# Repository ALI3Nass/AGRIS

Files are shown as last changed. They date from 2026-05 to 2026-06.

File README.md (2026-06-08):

# AGRIS

A computer vision-driven laser targeting system mounted on a remotely controlled mecanum platform. The system detects geometric shapes in a live camera feed and automatically aims a laser at them using a pan/tilt servo gimbal — while a separate subsystem handles omnidirectional drive via a controller.

---

<p align="center">
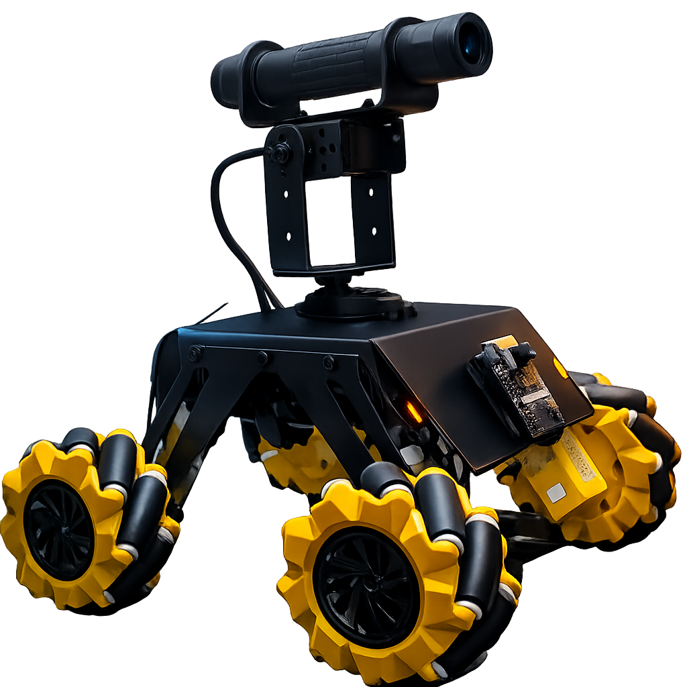
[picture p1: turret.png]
AGRIS turret assembly
  
</p>

---

## How it works

Two independent subsystems share the same laser-cut metal frame:

**Vision / Targeting**
The OV2640 camera streams MJPEG video over Wi-Fi to `agris.py` on a Linux host. OpenCV detects target shapes, calculates the angular error from the frame center, and sends absolute servo positions via UDP to the AI-Thinker ESP32. The ESP32 drives two MG996R servos and gates the laser on confirmed lock.

**Drive**
An ESP32-S1 connects to a DualShock 4 over Bluetooth (Bluepad32) and independently drives four mecanum wheels — full omnidirectional movement, strafing, and in-place rotation.

```
OV2640 (fixed to frame)
  → MJPEG stream over Wi-Fi
  → agris.py on PC  (shape detection, FOV-aware proportional control)
  → UDP :4210  →  AI-Thinker ESP32
                    ├── MG996R pan servo   (GPIO 12)
                    ├── MG996R tilt servo  (GPIO 13)
                    └── Laser module       (GPIO 2)

DualShock 4 (Bluetooth)
  → ESP32-S1
      ├── Mecanum FL
      ├── Mecanum FR
      ├── Mecanum RL
      └── Mecanum RR
```

---

## Hardware

| Component | Details |
|---|---|
| Vision + servo controller | AI-Thinker ESP32-CAM (OV2640) |
| Drive controller | ESP32-S1 |
| Camera | OV2640 — QVGA (320×240) for low latency |
| Servos | MG996R × 2 (pan / tilt) |
| Laser | LaserTree LT-40W-F23 (~5 W optical, 12 V / 1.8 A, PWM via signal wire) |
| Controller | DualShock 4 over Bluetooth |
| Frame | Laser-cut metal — DXF files in `CAD_Design/` |

---

## Repository layout

```
agris.py                     Python tracking app (GUI, detection, UDP sender)
AGRIS_AiThinker/
  AGRIS_AiThinker.ino        AI-Thinker firmware (MJPEG stream + UDP + servo/laser)
ESP32S1/
  ESP32S1.ino                Mecanum drive firmware (DualShock 4 → motors)
CAD_Design/
  part-1.dxf
  part-2.dxf
  part-3.dxf
  turret.jpg
```

---

## Setup

**Python dependencies**
```bash
pip install opencv-python numpy pillow requests
```

**Arduino libraries**
`esp32-camera` · `ESP32Servo` · `AsyncUDP` · `Bluepad32`

Flash `AGRIS_AiThinker.ino` to the AI-Thinker board and `ESP32S1.ino` to the drive controller, then run:
```bash
python agris.py
```

---

## Vision pipeline

Adaptive thresholding + contour classification. Detectable shapes:

- Rectangle
- Square
- Circle
- Plus cross `+`
- X cross `×`

Target priority and per-shape enable/disable are configurable at runtime in the GUI.

---

## Communication protocol

UDP packet sent from `agris.py` → ESP32 on port **4210**:

```
PAN:xxxx,TILT:xxxx,LASER:x
```

Values are microseconds for the servo signal. `LASER` is `0` or `1`.

**Servo ranges**

| Axis | Min | Center | Max |
|---|---|---|---|
| Pan | 500 µs | 1632 µs | 2500 µs |
| Tilt | 1050 µs | 1500 µs | 2200 µs |

Tracking uses one-shot absolute positioning — servo angles are computed directly from pixel error and camera FOV, not accumulated incrementally.

---

## Notes

- The laser pin (GPIO 2) is held LOW during boot to prevent accidental firing on startup.
- AI-Thinker board uses `CAMERA_FB_IN_DRAM` with `fb_count=1` (no PSRAM).
- An ESP32-S3 sketch is available as an alternate board target for the vision/servo role.
- The phone camera (IP Webcam → OpenCV HTTP URL) works as a drop-in fallback if the ESP32-CAM is unavailable.

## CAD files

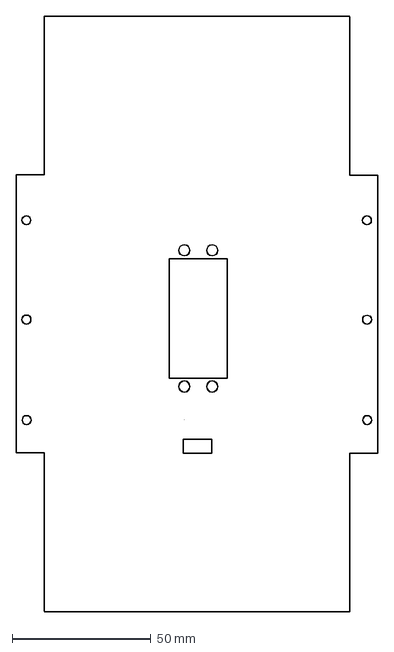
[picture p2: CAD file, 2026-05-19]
CAD_Design/part-2.dxf
130.0 x 214.2 mm

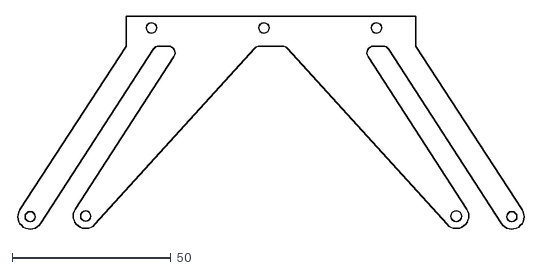
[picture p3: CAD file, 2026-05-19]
CAD_Design/part-1.dxf
160.8 x 67.7

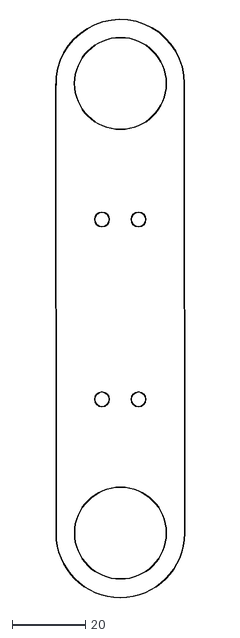
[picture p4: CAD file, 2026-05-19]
CAD_Design/part-3.dxf
35.2 x 158.3

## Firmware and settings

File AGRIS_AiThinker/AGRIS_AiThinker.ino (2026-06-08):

#include "esp_camera.h"
#include <WiFi.h>
#include <WebServer.h>
#include <ESP32Servo.h>
#include <AsyncUDP.h>

// ── WiFi ─────────────────────────────────────────────────────
const char* SSID     = "Pixel 9";
const char* PASSWORD = "12341234";
#define UDP_PORT 4210

// ── Pin Definitions ──────────────────────────────────────────
// No SD card used → GPIO 12 and 13 are free
// GPIO 2 is safe for digital output (ignore the brief boot LED blink)
#define SERVO_PAN_PIN   12    // ⚠ strapping pin — leave floating/low during boot
#define SERVO_TILT_PIN  13
#define LASER_PIN        2

// ── Camera Pins — AI-Thinker ESP32-CAM (OV2640) ──────────────
// Source: randomnerdtutorials.com/esp32-cam-ai-thinker-pinout/
#define PWDN_GPIO_NUM   32    // Active LOW — must be driven
#define RESET_GPIO_NUM  -1
#define XCLK_GPIO_NUM    0
#define SIOD_GPIO_NUM   26
#define SIOC_GPIO_NUM   27
#define Y9_GPIO_NUM     35
#define Y8_GPIO_NUM     34
#define Y7_GPIO_NUM     39
#define Y6_GPIO_NUM     36
#define Y5_GPIO_NUM     21
#define Y4_GPIO_NUM     19
#define Y3_GPIO_NUM     18
#define Y2_GPIO_NUM      5
#define VSYNC_GPIO_NUM  25
#define HREF_GPIO_NUM   23
#define PCLK_GPIO_NUM   22

// ── Servo range — synced with agris.py ───────────────────────
#define PAN_SERVO_MIN     500
#define PAN_SERVO_MAX    2500
#define PAN_SERVO_CENTER 1632
#define TILT_SERVO_MIN   1050
#define TILT_SERVO_MAX   2200
#define TILT_SERVO_CENTER 1500

Servo panServo;
Servo tiltServo;
WebServer server(80);
AsyncUDP udp;

int  currentPan  = PAN_SERVO_CENTER;
int  currentTilt = TILT_SERVO_CENTER;
bool laserOn     = false;

// ── Camera Setup ─────────────────────────────────────────────
void setupCamera() {
  camera_config_t config;

  // LEDC channel/timer: camera driver uses LEDC for XCLK generation.
  // Timers 0 and 1 can conflict — use 0 here as the camera itself
  // manages XCLK via LEDC_CHANNEL_0 / LEDC_TIMER_0 internally.
  config.ledc_channel = LEDC_CHANNEL_0;
  config.ledc_timer   = LEDC_TIMER_0;

  config.pin_d0    = Y2_GPIO_NUM;
  config.pin_d1    = Y3_GPIO_NUM;
  config.pin_d2    = Y4_GPIO_NUM;
  config.pin_d3    = Y5_GPIO_NUM;
  config.pin_d4    = Y6_GPIO_NUM;
  config.pin_d5    = Y7_GPIO_NUM;
  config.pin_d6    = Y8_GPIO_NUM;
  config.pin_d7    = Y9_GPIO_NUM;
  config.pin_xclk  = XCLK_GPIO_NUM;
  config.pin_pclk  = PCLK_GPIO_NUM;
  config.pin_vsync = VSYNC_GPIO_NUM;
  config.pin_href  = HREF_GPIO_NUM;

  // AI-Thinker uses older esp32-camera API naming (pin_sscb_*)
  // If your esp32-camera library uses pin_sccb_*, swap these:
  config.pin_sscb_sda = SIOD_GPIO_NUM;
  config.pin_sscb_scl = SIOC_GPIO_NUM;

  config.pin_pwdn  = PWDN_GPIO_NUM;   // GPIO 32 — must be set LOW to power camera
  config.pin_reset = RESET_GPIO_NUM;  // -1 = software reset

  config.xclk_freq_hz = 20000000;
  config.pixel_format = PIXFORMAT_JPEG;
  config.frame_size   = FRAMESIZE_QVGA;  // 320x240 — optimal for tracking
  config.jpeg_quality = 12;              // 0=best, 63=worst
  config.fb_count     = 2;

  // AI-Thinker PSRAM malloc failed — use internal DRAM instead.
  // Limit fb_count to 1 to avoid running out of DRAM.
  config.fb_location = CAMERA_FB_IN_DRAM;
  config.fb_count    = 1;
  config.grab_mode   = CAMERA_GRAB_WHEN_EMPTY;

  esp_err_t err = esp_camera_init(&config);
  if (err != ESP_OK) {
    Serial.printf("Camera init FAILED: 0x%x\n", err);
    Serial.println("Check: PSRAM present? Try fb_location = CAMERA_FB_IN_DRAM if this fails.");
  } else {
    Serial.println("Camera init OK");
  }

  // Sensor tuning after init
  sensor_t* s = esp_camera_sensor_get();
  if (s) {
    s->set_framesize(s,     FRAMESIZE_QVGA);
    s->set_quality(s,       12);
    s->set_brightness(s,     1);  // -2 to 2
    s->set_contrast(s,       1);  // -2 to 2
    s->set_saturation(s,     0);  // -2 to 2
    s->set_whitebal(s,       1);  // auto white balance
    s->set_awb_gain(s,       1);
    s->set_exposure_ctrl(s,  1);  // auto exposure
  }
}

// ── MJPEG Stream Handler ─────────────────────────────────────
void handleStream() {
  WiFiClient client = server.client();
  String response = "HTTP/1.1 200 OK\r\n";
  response += "Content-Type: multipart/x-mixed-replace; boundary=frame\r\n\r\n";
  server.sendContent(response);

  while (client.connected()) {
    camera_fb_t* fb = esp_camera_fb_get();
    if (!fb) {
      Serial.println("Frame capture failed, skipping");
      delay(10);
      continue;
    }

    String header = "--frame\r\nContent-Type: image/jpeg\r\nContent-Length: ";
    header += fb->len;
    header += "\r\n\r\n";
    server.sendContent(header);
    client.write(fb->buf, fb->len);
    server.sendContent("\r\n");
    esp_camera_fb_return(fb);
  }
}

// ── UDP Command Parser ───────────────────────────────────────
// Packet format: "PAN:1500,TILT:1400,LASER:1"
void setupUDP() {
  if (udp.listen(UDP_PORT)) {
    Serial.printf("UDP listening on port %d\n", UDP_PORT);
    udp.onPacket([](AsyncUDPPacket packet) {
      String msg = String((char*)packet.data(), packet.length());

      Serial.print("UDP rx: ");
      Serial.println(msg);  // Keep this for debugging — remove once confirmed working

      int pIdx = msg.indexOf("PAN:");
      int tIdx = msg.indexOf("TILT:");
      int lIdx = msg.indexOf("LASER:");

      if (pIdx >= 0) {
        int panVal = msg.substring(pIdx + 4, msg.indexOf(',', pIdx)).toInt();
        currentPan = constrain(panVal, PAN_SERVO_MIN, PAN_SERVO_MAX);
        panServo.writeMicroseconds(currentPan);
      }
      if (tIdx >= 0) {
        int tiltVal = msg.substring(tIdx + 5, msg.indexOf(',', tIdx)).toInt();
        currentTilt = constrain(tiltVal, TILT_SERVO_MIN, TILT_SERVO_MAX);
        tiltServo.writeMicroseconds(currentTilt);
      }
      if (lIdx >= 0) {
        laserOn = msg.substring(lIdx + 6).toInt();
        digitalWrite(LASER_PIN, laserOn ? HIGH : LOW);
      }
    });
  } else {
    Serial.println("UDP listen FAILED");
  }
}

// ── Setup ─────────────────────────────────────────────────────
void setup() {
  Serial.begin(115200);
  Serial.println("\nBooting AI-Thinker ESP32-CAM AGRIS...");

  // Laser — GPIO 2
  // Note: GPIO2 has a built-in pull-down and is connected to the onboard
  // blue LED on some boards. It may blink briefly on boot — this is normal.
  pinMode(LASER_PIN, OUTPUT);
  digitalWrite(LASER_PIN, LOW);

  // Servos — use LEDC timers 2 & 3 to avoid conflict with camera XCLK
  // (camera driver claims timers 0 and 1 via LEDC_CHANNEL_0 / LEDC_TIMER_0)
  ESP32PWM::allocateTimer(2);
  ESP32PWM::allocateTimer(3);
  panServo.setPeriodHertz(50);
  tiltServo.setPeriodHertz(50);
  panServo.attach(SERVO_PAN_PIN,   PAN_SERVO_MIN, PAN_SERVO_MAX);
  tiltServo.attach(SERVO_TILT_PIN, TILT_SERVO_MIN, TILT_SERVO_MAX);
  panServo.writeMicroseconds(PAN_SERVO_CENTER);
  tiltServo.writeMicroseconds(TILT_SERVO_CENTER);
  Serial.println("Servos centered");

  // Camera
  setupCamera();

  // WiFi — station mode
  WiFi.mode(WIFI_STA);
  WiFi.begin(SSID, PASSWORD);
  Serial.print("Connecting to WiFi");
  int tries = 0;
  while (WiFi.status() != WL_CONNECTED && tries < 30) {
    delay(500);
    Serial.print(".");
    tries++;
  }

  if (WiFi.status() == WL_CONNECTED) {
    Serial.println("\nWiFi connected!");
    Serial.println("IP:         " + WiFi.localIP().toString());
    Serial.println("Stream URL: http://" + WiFi.localIP().toString() + "/stream");
    Serial.println("Update agris.py ESP32_IP to: " + WiFi.localIP().toString());
  } else {
    Serial.println("\nWiFi FAILED — check SSID/password");
  }

  // HTTP stream server
  server.on("/stream", handleStream);
  server.begin();
  Serial.println("HTTP server started");

  // UDP
  setupUDP();

  Serial.println("Ready!");
}

// ── Loop ──────────────────────────────────────────────────────
void loop() {
  server.handleClient();
}

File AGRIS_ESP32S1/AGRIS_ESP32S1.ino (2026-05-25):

#include <Arduino.h>
#include <Bluepad32.h>
#include "soc/soc.h"
#include "soc/rtc_cntl_reg.h"

/* ================= PIN DEFINITIONS ================= */
// Driver 1 — Left side
#define FL_IN1   32    // AIN1
#define FL_IN2   33    // AIN2
#define FL_PWM   25    // PWMA  → Front-Left motor

#define RL_IN1   26    // BIN1
#define RL_IN2   27    // BIN2
#define RL_PWM   14    // PWMB  → Rear-Left motor

// Driver 2 — Right side
#define FR_IN1   19    // AIN1
#define FR_IN2   18    // AIN2
#define FR_PWM   23    // PWMA  → Front-Right motor

#define RR_IN1   17    // BIN1
#define RR_IN2   21    // BIN2
#define RR_PWM   16    // PWMB  → Rear-Right motor

// Shared STBY
#define STBY_PIN 13

/* ================= PWM CONFIG ================= */
#define PWM_FREQ   1000
#define PWM_RES    8
#define CH_FL      0
#define CH_RL      1
#define CH_FR      2
#define CH_RR      3

/* ================= TUNING ================= */
#define DEADZONE    10
#define MAX_FWD     175
#define MAX_STR     110
#define MAX_ROT     90
#define EXPO        2.2f
#define RAMP_STEP   5
#define LED_PIN     2

// Calibration — tweak if one wheel is faster than others
#define FL_GAIN  1.00f
#define FR_GAIN  1.00f
#define RL_GAIN  1.00f
#define RR_GAIN  1.00f

/* ================= GLOBALS ================= */
ControllerPtr myControllers[BP32_MAX_GAMEPADS];

int g_fwd = 0, g_str = 0, g_rot = 0;
bool g_stop = false;

int cur_fl = 0, cur_fr = 0, cur_rl = 0, cur_rr = 0;

/* ================= EXPO + AXIS PROCESSING ================= */
int processAxis(int val, int maxOut) {
  if (abs(val) < DEADZONE) return 0;
  float normalized = (float)(abs(val) - DEADZONE) / (512.0f - DEADZONE);
  normalized = constrain(normalized, 0.0f, 1.0f);
  float curved = pow(normalized, EXPO);
  return (int)((val > 0 ? 1.0f : -1.0f) * curved * maxOut);
}

/* ================= RAMP HELPER ================= */
int rampTo(int current, int target) {
  if (current < target) return min(current + RAMP_STEP, target);
  if (current > target) return max(current - RAMP_STEP, target);
  return current;
}

/* ================= MOTOR FUNCTIONS ================= */
void stopMotors() {
  cur_fl = cur_fr = cur_rl = cur_rr = 0;
  ledcWrite(CH_FL, 0); ledcWrite(CH_FR, 0);
  ledcWrite(CH_RL, 0); ledcWrite(CH_RR, 0);
  digitalWrite(FL_IN1, LOW); digitalWrite(FL_IN2, LOW);
  digitalWrite(FR_IN1, LOW); digitalWrite(FR_IN2, LOW);
  digitalWrite(RL_IN1, LOW); digitalWrite(RL_IN2, LOW);
  digitalWrite(RR_IN1, LOW); digitalWrite(RR_IN2, LOW);
}

void setMotor(int ch, int in1, int in2, int spd) {
  spd = constrain(spd, -255, 255);
  if (spd > 0) {
    digitalWrite(in1, HIGH); digitalWrite(in2, LOW);
  } else if (spd < 0) {
    digitalWrite(in1, LOW);  digitalWrite(in2, HIGH);
  } else {
    digitalWrite(in1, LOW);  digitalWrite(in2, LOW);
  }
  ledcWrite(ch, abs(spd));
}

void mecanumDrive(int fwd, int str, int rot) {
  // Standard mecanum mixing
  int fl = fwd + str + rot;
  int fr = fwd - str - rot;
  int rl = fwd - str + rot;
  int rr = fwd + str - rot;

  // Normalise — scale down only, never up
  int maxAbs = max({abs(fl), abs(fr), abs(rl), abs(rr)});
  if (maxAbs > 255) {
    fl = (int)((long)fl * 255 / maxAbs);
    fr = (int)((long)fr * 255 / maxAbs);
    rl = (int)((long)rl * 255 / maxAbs);
    rr = (int)((long)rr * 255 / maxAbs);
  }

  // Ramp
  cur_fl = rampTo(cur_fl, fl);
  cur_fr = rampTo(cur_fr, fr);
  cur_rl = rampTo(cur_rl, rl);
  cur_rr = rampTo(cur_rr, rr);

  // Send — apply gain for calibration
  setMotor(CH_FL, FL_IN1, FL_IN2, (int)(cur_fl * FL_GAIN));
  setMotor(CH_FR, FR_IN1, FR_IN2, (int)(cur_fr * FR_GAIN));
  setMotor(CH_RL, RL_IN1, RL_IN2, (int)(cur_rl * RL_GAIN));
  setMotor(CH_RR, RR_IN1, RR_IN2, (int)(cur_rr * RR_GAIN));
}

/* ================= BLUEPAD32 CALLBACKS ================= */
void onConnectedController(ControllerPtr ctl) {
  for (int i = 0; i < BP32_MAX_GAMEPADS; i++) {
    if (!myControllers[i]) {
      myControllers[i] = ctl;
      digitalWrite(LED_PIN, HIGH);
      Serial.printf("Controller connected at slot %d\n", i);
      break;
    }
  }
}

void onDisconnectedController(ControllerPtr ctl) {
  for (int i = 0; i < BP32_MAX_GAMEPADS; i++) {
    if (myControllers[i] == ctl) {
      myControllers[i] = nullptr;
      stopMotors();
      digitalWrite(LED_PIN, LOW);
      Serial.println("Controller disconnected — motors stopped");
      break;
    }
  }
}

/* ================= PROCESS INPUT ================= */
void processGamepad(ControllerPtr ctl) {
  // Cross (X) = emergency stop
  if (ctl->buttons() & BUTTON_A) {
    g_fwd = 0; g_str = 0; g_rot = 0;
    g_stop = true;
    return;
  }
  g_stop = false;

  g_fwd = processAxis(ctl->axisY(),  MAX_FWD);
  g_str = processAxis(ctl->axisX(),  MAX_STR);
  g_rot = processAxis(ctl->axisRX(), MAX_ROT);

  // L1 = slow mode
  if (ctl->buttons() & BUTTON_SHOULDER_L) {
    g_fwd /= 2;
    g_str /= 2;
    g_rot /= 2;
  }
}

void processControllers() {
  for (auto ctl : myControllers) {
    if (ctl && ctl->isConnected() && ctl->isGamepad()) {
      processGamepad(ctl);
    }
  }
}

/* ================= SETUP ================= */
void setup() {
  WRITE_PERI_REG(RTC_CNTL_BROWN_OUT_REG, 0);
  Serial.begin(115200);

  pinMode(LED_PIN, OUTPUT);
  digitalWrite(LED_PIN, LOW);

  // STBY — must be HIGH for drivers to operate
  pinMode(STBY_PIN, OUTPUT);
  digitalWrite(STBY_PIN, HIGH);

  // Direction pins
  int dirPins[] = {
    FL_IN1, FL_IN2, FR_IN1, FR_IN2,
    RL_IN1, RL_IN2, RR_IN1, RR_IN2
  };
  for (int p : dirPins) {
    pinMode(p, OUTPUT);
    digitalWrite(p, LOW);
  }

  // PWM setup
  ledcSetup(CH_FL, PWM_FREQ, PWM_RES); ledcAttachPin(FL_PWM, CH_FL);
  ledcSetup(CH_FR, PWM_FREQ, PWM_RES); ledcAttachPin(FR_PWM, CH_FR);
  ledcSetup(CH_RL, PWM_FREQ, PWM_RES); ledcAttachPin(RL_PWM, CH_RL);
  ledcSetup(CH_RR, PWM_FREQ, PWM_RES); ledcAttachPin(RR_PWM, CH_RR);

  stopMotors();

  BP32.setup(&onConnectedController, &onDisconnectedController);

  Serial.println("==============================");
  Serial.println("  Mecanum DS4 — TB6612FNG");
  Serial.println("==============================");
  Serial.println("Waiting for controller...");
  Serial.println("Press PS button on DS4");
}

/* ================= LOOP ================= */
void loop() {
  BP32.update();
  processControllers();

  if (g_stop) {
    stopMotors();
  } else {
    mecanumDrive(g_fwd, g_str, g_rot);
  }

  delay(10);
}

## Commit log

2026-05-25 swap motor driver L298N → TB6612FNG
    [AGRIS_ESP32S1.ino]
2026-06-08 camera setup and UDP command parsing
    Refactor code to integrate camera functionality and UDP command handling.
2026-06-08 turret assembly image
